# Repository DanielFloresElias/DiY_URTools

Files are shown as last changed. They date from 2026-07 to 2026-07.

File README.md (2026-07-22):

# Herramientas DIY para Robots Colaborativos (UR)

Este proyecto se centra en el **diseño, fabricación e integración de herramientas de bajo coste** para cobots de Universal Robots, utilizando procesos de fabricación DIY (Do It Yourself) y su aplicación en entornos industriales y educativos.

## 📋 Descripción del Proyecto
El objetivo principal ha sido desarrollar un ecosistema de herramientas funcionales (como pinzas y sistemas de iluminación) que se integran nativamente con el software del robot mediante **URCaps**. Esto permite a centros de formación y pequeñas industrias acceder a aplicaciones de robótica colaborativa sin los altos costes de las herramientas comerciales.

## 🚀 Características Técnicas
*   **Controlador:** Basado en ESP32-WROOM-32 con conectividad Ethernet (W5500).
*   **Comunicación:** Protocolo TCP/IP mediante buffers cíclicos de 32 bytes para el intercambio de datos en tiempo real.
*   **Actuadores:** Control de motores con PID y monitorización de corriente.
*   **Interfaz:** Integración completa en PolyScope mediante URCaps personalizadas.

## 📁 Estructura del Repositorio
*   `docs/`: Documentación técnica y especificaciones.
*   `hardware/`: Esquemas eléctricos y diseño de la PCB.
*   `firmware/`: Código C++ para el sistema de control.
*   `software/`: Código de las URCaps y app de configuración.
*   `mecanica/`: Modelos 3D para impresión.
*   `URcaps/`: URcaps para instalar en Polyscope.

## 👥 Centros Participantes
Este proyecto ha sido una colaboración entre:
*   **IES La Valldigna** (Centro coordinador)
*   **IES Jaume Huguet**
*   **Institut Tecnològic de Barcelona**
*   **IES Federica Montseny**
*   **Universal Robots España** (Apoyo técnico y formación)

## 💰 Financiación

Este proyecto ha sido posible gracias a la financiación de las siguientes instituciones:

<table>
  <tr>
    <td align="center" width="33%">
      Ministerio de Educación, FP y Deportes
    </td>
    <td align="center" width="33%">
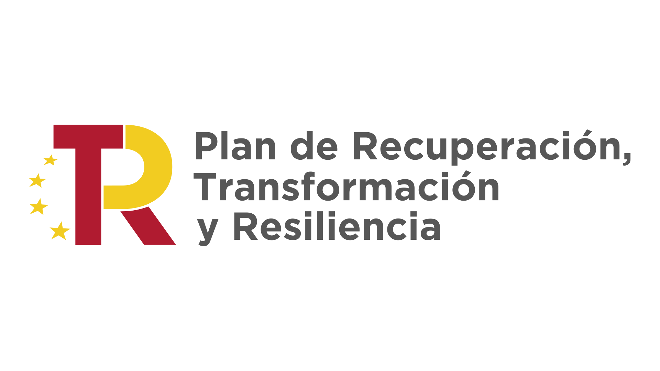
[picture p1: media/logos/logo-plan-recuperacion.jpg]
Plan de Recuperación, Transformación y Resiliencia
      
    </td>
    <td align="center" width="33%">
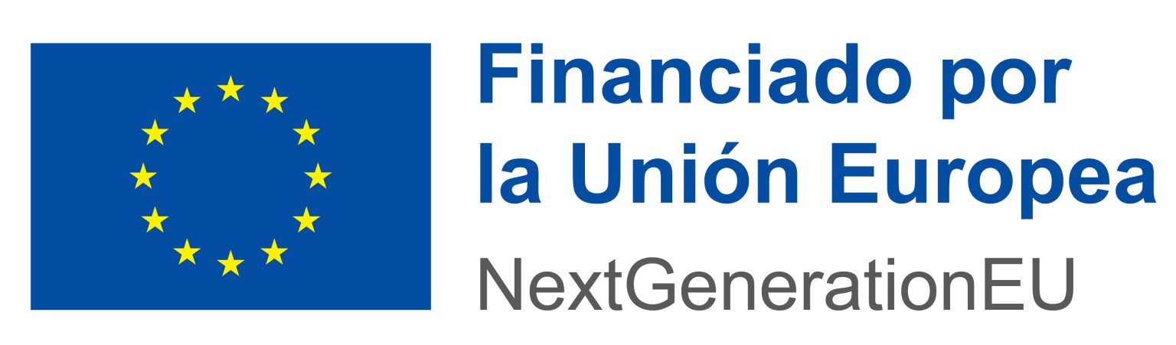
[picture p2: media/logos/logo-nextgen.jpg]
Financiado por la Unión Europea NextGenerationEU
      
    </td>
  </tr>
</table>

Proyecto financiado por el **Ministerio de Educación, Formación Profesional y Deportes** y la **Unión Europea (NextGenerationEU)** en el marco del Plan de Recuperación, Transformación y Resiliencia.

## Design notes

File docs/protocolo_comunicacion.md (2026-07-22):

# Especificaciones del Protocolo de Comunicación DiY_URTools

Este documento detalla el protocolo de intercambio de datos entre el robot Universal Robots (cliente) y la herramienta DiY (servidor TCP) basado en el controlador ESP32.

## 📡 Arquitectura de Red
*   **Protocolo:** TCP/IP Sockets.
*   **Puerto por defecto:** `30002`.
*   **Modo de conexión:** Ciclo de actualización de 100ms (10Hz) para garantizar tiempo real.
*   **Estructura de datos:** Intercambio de tramas fijas de **32 bytes** en ambos sentidos (Full-Duplex).

## 📥 OUT_Buffer (Robot -> Herramienta)
Define las acciones y consignas que el robot envía a la herramienta.

| Byte | Nombre | Descripción | Rango / Valores |
| :--- | :--- | :--- | :--- |
| **0** | **Flags de Acción** | Bits de control (ver detalle abajo) | 8 bits |
| **1** | **Efecto LED** | Tipo de efecto para el anillo luminoso | 0 - 7 |
| **2** | **Consigna (Setpoint)** | Posición deseada de la pinza | 0 (Abierto) - 255 (Cerrado) |
| **3** | **Color 1** | Color principal (ver tabla de colores) | 0 - 15 |
| **4** | **Color 2** | Color secundario para efectos duales | 0 - 15 |
| **5** | **Intervalo** | Velocidad del efecto luminoso | 1 - 255 |

### Detalle de Flags (Byte 0):
*   **Bit 0:** Abrir pinza (Open).
*   **Bit 1:** Cerrar pinza (Close).
*   **Bit 2:** Abrir manual (Override).
*   **Bit 3:** Cerrar manual (Override).

## 📤 IN_Buffer (Herramienta -> Robot)
Contiene la retroalimentación del estado de la herramienta.

| Byte | Nombre | Descripción | Rango / Valores |
| :--- | :--- | :--- | :--- |
| **0** | **Flags de Estado** | Estado de sensores y confirmación | 8 bits |
| **2** | **Posición Actual** | Lectura real del encoder del motor | 0 - 255 |
| **29** | **Modelo** | Identificador del modelo de hardware | ASCII / ID |
| **30-31**| **Firmware Ver.** | Versión del firmware instalada | vX.Y |

## 🎨 Tabla de Colores e Indicadores
El motor de efectos soporta 16 colores predefinidos (Byte 3 y 4), incluyendo:
0: Rojo, 1: Verde, 2: Azul, 3: Amarillo, 4: Magenta, 5: Cian, 8: Blanco, 15: Apagado.

### Efectos Disponibles (Byte 1):
0: Sin efecto, 1: Sólido, 2: Respiración, 3: Knight Rider, 4: Policía, 5: Flash, 6: Arcoíris.
2. Contenido para docs/guia_uso.md
# Guía de Uso e Integración

Esta guía explica cómo poner en marcha las herramientas DiY_URTools e integrarlas en el ecosistema de Universal Robots.

## 🛠️ Requisitos Previos
1.  **Hardware:** PCB DiY_URTools montada con ESP32 y módulo Ethernet W5500.
2.  **Alimentación:** Conector de 12V/24V según el motor utilizado.
3.  **Software:** Robot con PolyScope 5.x o superior.

## ⚙️ Configuración de Red
La herramienta puede configurarse de dos formas:

1.  **Herramienta de Configuración (Python):** Ejecutar `URToolConfigApp` conectando el ESP32 por USB para asignar la IP estática, Máscara y Puerta de enlace.
2.  **Modo Programación:** El firmware incluye un `CONFIGURATION_MODE` que permite el ajuste de parámetros PID (`pinces.setPID(0.4, 0.05, 2.0)`) y límites de fuerza por software para evitar daños en las piezas.

## 🤖 Integración en PolyScope
Para utilizar la herramienta en un programa de robot:

1.  **Instalación de la URCap:** Cargar el archivo `.urcap` generado por el Institut Tecnològic de Barcelona.
2.  **Configuración del Nodo:**
    *   Ir a la pestaña de "Instalación" -> "DiYTool".
    *   Introducir la dirección IP asignada a la herramienta.
    *   Verificar la conexión (el indicador LED de la herramienta debería cambiar de estado).
3.  **Programación:**
    *   Utilizar los nodos de estructura para abrir/cerrar la pinza.
    *   Configurar los efectos visuales para indicar estados (ej: Rojo = Error, Verde = Operación normal).

## ⚠️ Mantenimiento y Seguridad
*   **Detección de pieza:** El sistema monitoriza el consumo de corriente. Si la corriente supera el `gripCurrentThreshold`, la pinza detecta que ha sujetado un objeto y detiene el movimiento.
*   **Watchdog:** El firmware incluye un sistema de seguridad que detiene los motores si se pierde la comunicación TCP con el robot por más de 500ms.

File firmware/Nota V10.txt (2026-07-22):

Aquesta versió incorpora la possibilitat de modificar la configuración de xarxa mitjançant comandes pel port Sèrie.

Com utilitzar les noves comandes Serial
1.Carrega el codi a l'ESP32.
2. Obre el Monitor Serial (a 115200 baudis).
3. Escriu una de les següents comandes i prem ENTER:

Comanda			Funció									Exemple

STATUS			Mostra la configuració IP, MASK i Gateway actualment carregada.		STATUS

IP <adreça>		Canvia temporalment l'adreça IP de l'eina.				IP 192.168.5.100

MASK <adreça>		Canvia temporalment la Subnet Mask.					MASK 255.255.0.0

GW <adreça>		Canvia temporalment el Gateway.						GW 192.168.5.1

SAVE			Guarda permanentment la configuració temporal a l'EEPROM.SAVEREINICIA (Manual)Després de SAVE, has de reiniciar l'ESP32 per aplicar la nova configuració d'Ethernet.(Prem el botó RESET)

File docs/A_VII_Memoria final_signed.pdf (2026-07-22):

ANEXO VII

MODELO DE MEMORIA FINAL DEL PROYECTO

Título del Proyecto: | “Diseño, fabricación e integración de herramientas para robots colaborativos (UR) a partir de procesos de fabricación DIY y aplicación en procesos industriales”
Centro educativo coordinador del proyecto: | IES La Valldigna
Línea o líneas temáticas: | Línea 1, Línea 2, Línea 3, Línea 4, Línea 5, Línea 6
Duración del proyecto: | 20 meses (Sept 2024 - Abril 2026)
Participantes en el proyecto: | IES La Valldigna IES Jaume Huguet Institut Tecnològic de Barcelona IES Federica Montseny
Miembros | Denominación (centro, empresa, entidad) | Funciones desarrolladas | Datos de contacto
Centro coordinador: | IES La Valldigna | Diseño y fabricación de herramienta para el robot colaborativo y su comunicación con el robot | Calle Sant Benet, 249 46760 Tavernes de la Valldigna, València
Participante 2: | Universal Robots España | Formación en robótica colaborativa y apoyo en la programación de UR Caps | Calle Agricultura 106, 08019, Barcelona, Barcelona
Participante 3: | IES Jaume Huguet | Diseño y fabricación de herramienta para el robot colaborativo y su comunicación con el robot | Calle Creu de Cames, SN 43800, Valls, Tarragona
Participante 4: | Institut Tecnològic de Barcelona | Desarrollo del software UR Caps para la comunicación con las distintas herramientas | Calle Aiguablava 121 08033 Barcelona, Barcelona
Participante 5: | IES Federica Montseny | Diseño y fabricación de herramienta para el robot colaborativo | Avenida Primero de Mayo, 4, 46100, Burjassot, Valencia

FORMACIÓN PROFESIONAL

1. Conclusiones sobre la innovación y transferencia conseguidas con el proyecto.
1.1. Breve resumen del proyecto, tras su finalización. Valoración de la relación del proyecto con los objetivos de la convocatoria, a la vista de cómo se ha desarrollado y de cuáles son los resultados conseguidos.

El proyecto “Diseño, fabricación e integración de herramientas para robots colaborativos (UR) a partir de procesos de fabricación DIY y aplicación en procesos industriales” ha permitido un trabajo conjunto entre centros de Formación Profesional de distintas comunidades autónomas y una empresa del sector de la robótica, presentando la oportunidad de compartir conocimientos y experiencias y mejorando la formación técnica del profesorado y, en último término, del alumnado en el ámbito de la robótica colaborativa. El proyecto está basado en el diseño, fabricación, integración y uso didáctico de herramientas de bajo coste para cobots Universal Robots, así como la generación de materiales formativos transferibles a otros contextos educativos y productivos.

El desarrollo del proyecto ha favorecido la colaboración efectiva entre los centros participantes y la empresa generando un entorno en el que se combina la aplicación educativa e industrial y la innovación tecnológica. Esta cooperación ha hecho posible no solo el desarrollo de herramientas plenamente funcionales de bajo coste, sino también la elaboración de documentación técnica, guías, prácticas, video-tutoriales y recursos reutilizables, además de la creación de URCaps y de un repositorio digital orientado a facilitar la replicabilidad del trabajo realizado por otros centros de FP. Entre los logros de este proyecto se encuentran, por tanto, la disponibilidad de herramientas finales utilizables en entornos de simulación de procesos industriales, la generación de materiales didácticos abiertos y la capacitación del alumnado en robótica colaborativa y en tecnologías vinculadas a la industria 4.0.

Durante el proyecto se ha mantenido una relación coherente con los objetivos de la convocatoria ya que ha conectado la formación de alumnado y profesorado con necesidades reales del proceso productivo, ha promovido el aprendizaje basado en retos y proyectos, ha fortalecido la cooperación entre centros y empresa y ha generado productos concretos transferibles al ámbito educativo y empresarial.

Del mismo modo, el proyecto mantiene una vinculación sólida con las líneas temáticas de la convocatoria. Se ha centrado en la innovación tecnológica y en la transferencia de conocimiento entre empresa y centros (Línea 1); ha desarrollado competencias relacionadas con la digitalización, la automatización y la industria 4.0 (Línea 2) y ha impulsado metodologías activas mediante retos interdisciplinares y proyectos vinculados a aplicaciones industriales (Línea 5). Asimismo, el proyecto ha incorporado elementos que relacionados con las vocaciones STEAM haciendo énfasis en la visibilización de la mujer en entornos tecnológicos (Línea 3); con la competencia emprendedora y la conexión con el tejido productivo (Línea 4); y con la creación de redes de colaboración estables e intercambio de conocimiento entre agentes del sector (Línea 6).

En términos generales, podría afirmarse que el proyecto ha cumplido satisfactoriamente con la finalidad de la convocatoria al generar un entorno compartido entre empresa y centros participantes, producir resultados en forma de herramientas para el robot UR tangibles y de valor, enriquecer la capacitación técnica y metodológica de los docentes y ampliar las posibilidades didácticas de los centros educativos en su afán de acercar al alumnado a tecnologías de valor estratégico en la industria actual y futura.

1.2. Descripción del valor añadido del proyecto, con indicación de los beneficios que para los centros educativos ha reportado.

La realización del proyecto ha supuesto un importante valor añadido para los centros educativos participantes, al permitir la movilización de conocimientos previos y su integración con nuevos aprendizajes vinculados a la robótica colaborativa, la fabricación de herramientas de bajo coste, la conectividad industrial y la aplicación didáctica de tecnologías propias de la industria 4.0.

En primer lugar, el proyecto ha contribuido de forma significativa a la mejora de la competencia técnica del profesorado en robótica colaborativa, especialmente en el manejo, programación e integración de robots Universal Robots. Esta formación ha tenido una repercusión directa en el alumnado, ya que los conocimientos adquiridos por los docentes se han transferido al aula mediante actividades prácticas, retos y proyectos vinculados a situaciones próximas al entorno industrial. De este modo, el proyecto no solo ha favorecido la actualización tecnológica del profesorado, sino también la mejora de la calidad de la enseñanza en los ciclos formativos implicados.

Asimismo, el diseño y la construcción de diferentes herramientas para el robot colaborativo ha ampliado notablemente las posibilidades didácticas de los equipos disponibles en los centros. Anteriormente, la explotación didáctica del robot colaborativo se limitaba a herramientas comerciales que limitaban, por su coste, las situaciones de aplicación del robot. Ahora, con las herramientas diseñadas, se amplían.

Otro beneficio relevante ha sido el desarrollo de metodologías activas en el aula, especialmente mediante el aprendizaje basado en retos y proyectos. El alumnado ha podido participar en tareas con un producto final tangible, tomar decisiones técnicas, documentar procesos, ensayar soluciones, detectar errores y proponer mejoras. Esta dinámica ha contribuido al desarrollo de competencias transversales como el trabajo en equipo, la autonomía, la iniciativa, la comunicación técnica y la capacidad de adaptación ante problemas reales.

Además, el proyecto ha generado un beneficio organizativo y pedagógico para los centros, al impulsar la colaboración entre departamentos, familias profesionales y especialidades docentes. La robótica colaborativa ha actuado como eje integrador para conectar conocimientos de automatización, electricidad, electrónica, fabricación mecánica, diseño, programación y comunicaciones industriales. Esta colaboración ha permitido enriquecer las programaciones didácticas y abrir la puerta a futuras actividades intermodulares o proyectos de centro.

Desde el punto de vista de la transferencia, el proyecto ha permitido generar conocimiento y materiales reutilizables que podrán ser aprovechados por los propios centros participantes y por otros centros de Formación Profesional. La elaboración de documentación, guías, tutoriales y recursos vinculados al diseño, fabricación e integración de herramientas DIY para cobots refuerza la sostenibilidad del proyecto y facilita que sus resultados puedan mantenerse y ampliarse más allá del periodo de ejecución.

Por último, el proyecto ha favorecido la creación de una red de colaboración entre docentes de distintos centros educativos y especialidades, lo que ha supuesto un intercambio enriquecedor de experiencias, soluciones técnicas y enfoques metodológicos. Esta cooperación ha permitido comparar realidades educativas diferentes, compartir recursos, resolver dificultades comunes y avanzar en innovación.

1.3. Expectativas de continuidad y/o institucionalización de las actividades realizadas o desarrollos conseguidos en el marco del proyecto.

La valoración positiva de los resultados alcanzados permite prever la continuidad de varias de las actividades, metodologías y desarrollos generados en el marco del proyecto. Más allá de la ejecución de las acciones previstas, el proyecto ha creado una base técnica, metodológica y organizativa que podrá ser aprovechada por los centros participantes en cursos posteriores.

En primer lugar, se prevé consolidar el uso de metodologías activas, especialmente el aprendizaje basado en retos y el aprendizaje basado en proyectos, como estrategia para favorecer la implicación del alumnado y el desarrollo de competencias profesionales y transversales. Este enfoque ha permitido trabajar no solo contenidos técnicos vinculados a la robótica colaborativa, sino también habilidades como la autonomía, la resolución de problemas, la comunicación técnica, la toma de decisiones, la creatividad y el trabajo en equipo.

Asimismo, los conocimientos adquiridos por el profesorado y el alumnado en el diseño, fabricación e integración de herramientas para robots colaborativos permitirán seguir desarrollando nuevas aplicaciones didácticas en el futuro. La experiencia acumulada durante el proyecto abre la posibilidad de crear nuevos prototipos, mejorar los ya desarrollados y adaptar las soluciones generadas a otros módulos, ciclos formativos o necesidades concretas del entorno productivo.

Otro elemento que favorece la continuidad es la generación de materiales, documentación técnica, guías y recursos didácticos derivados del proyecto. Estos productos podrán incorporarse a las programaciones de distintos módulos profesionales y reutilizarse con nuevas promociones de alumnado, lo que contribuye a institucionalizar los aprendizajes obtenidos.

De igual modo, la colaboración entre los centros participantes representa una de las principales líneas de continuidad. La comunicación establecida durante el proyecto ha permitido compartir experiencias, resolver dificultades técnicas y metodológicas, contrastar soluciones y enriquecer la práctica docente. Esta red de trabajo podrá mantenerse para futuras colaboraciones, nuevas propuestas de innovación o actividades intercentros relacionadas con la robótica colaborativa, la automatización industrial, la fabricación digital o la industria 4.0.

Finalmente, la continuidad del proyecto podrá verse reflejada en la actualización progresiva de las programaciones didácticas, la incorporación de nuevas prácticas con robots colaborativos, la ampliación de los recursos disponibles en los talleres y la consolidación de una cultura de innovación aplicada en los centros. De este modo, los desarrollos conseguidos no se limitan a los productos generados durante el proyecto, sino que contribuyen a transformar de manera estable la forma en que se enseña y se aprende la robótica colaborativa en la Formación Profesional.

2. Memoria económica.
2.1. Cuantía total de la subvención recibida.

La cuantía total de la subvención recibida asciende a 120.000 €, recibiendo cada centro educativo 30.000 € y 0 € la empresa Universal Robots.

2.2. Gastos desagregados por participantes en el proyecto.
Miembros | Denominación (centro, empresa, entidad) | Funciones desarrolladas | Datos de contacto
Centro coordinador | IES La Valldigna | Centro coordinador. Diseño e implementación de herramientas | Calle Sant Benet, 249 46760 Tavernes de la Valldigna, València
Integrante 2 | Institut Jaume Huguet | Diseño e implementación de herramientas | Calle Creu de Cames, SN 43800, Valls, Tarragona
Integrante 3 | Institut Tecnològic Barcelona | Diseño y programación de URCaps | Calle Aiguablava 121 08033 Barcelona, Barcelona
Integrante 4 | IES Federica Montseny | Diseño e implementación de herramientas | Avenida Primero de Mayo, 4, 46100, Burjassot, Valencia
Integrante 5 | Universal Robots | Formador en robótica colaborativa | Calle Agricultura 106, 08019, Barcelona, Barcelona

3. Desarrollo del proyecto.
3.1. Índice de las acciones previstas inicialmente y que constaban en la Memoria técnica del proyecto.

En la siguiente tabla se especifican las diferentes fases y bloques de trabajo previstas inicialmente:

Fases | Bloque de trabajo
1 | Gestión del proyecto | 1.1 Coordinación de participantes y creación de un sistema de archivos compartido.

1.2 Elaboración de memoria inicial, de progreso y final.

2

Formación
profesorado robótica
colaborativa

2.1 Implementación y montaje de un sistema robótico de Universal Robots para realizar un proceso industrial.
2.2 Programación básica y avanzada de cobots de Universal Robots.

3

Estudio, diseño y
simulación digital de
herramientas

3.1 Estudio de las herramientas robóticas en aplicaciones industriales y sus principales características.
3.2 Diseño digital de herramientas robóticas mediante 3D CAD, implementando modelos de virtualización (gemelo digital)

4

Fabricación e
integración de las
herramientas de bajo
coste en robot UR

4.1 Estudio de procesos de fabricación en la industria clásica y las nuevas técnicas, métodos y materiales surgidos en la industria actual.
4.2 Implementación de procesos de fabricación por sustracción o deposición a partir de los modelos 3D CAD diseñados por los estudiantes. 4.3 Integración electrónica (hardware), programación de firmware (URCaps) y software para el control de la herramienta en la aplicación robótica.

5

Formación del
alumnado en robótica
colaborativa

5.1 Implementación y montaje de un sistema robótico de Universal Robots para realizar un proceso industrial.
5.2 Programación básica y avanzada de cobots de Universal Robots 5.3 Implementación de aplicaciones industriales de la industria local.

6

Retos a nivel centro
robótica colaborativa

6.1 Realización de aplicaciones industriales con cobots y con las herramientas diseñadas, verificando la funcionalidad de estas.
6.2 Realización de una jornada (“skills”) en cada centro para valorar las mejores herramientas diseñadas y sus prestaciones en entornos productivos con cobots.

7

Jornada de retos
intercentros robótica
colaborativa

7.1 Exponer y analizar el proceso de fabricación de herramientas de bajo coste a compañeros de otros centros educativos.
7.2 Realización de una jornada intercentros mediante un concurso del uso de cobots en aplicaciones industriales, así como diseño e implementación de herramientas low cost.

8

Elaboración de
documentación para
el desarrollo de
herramientas DIY

8.1 Realización de un repositorio de documentación para guiar a diseñar, fabricar e integrar herramientas “low cost” para cobots en función de las necesidades de la aplicación industrial.
8.2 Realización de un repositorio de documentación para programar robots colaborativos de UR, integrando herramientas de diseño propio en entornos industriales.
9 | Evaluación | 9.1 Análisis de la ejecución del proyecto, identificando fortalezas y

y difusión del
proyecto

debilidades, promoviendo posibles mejoras.
9.2 Difundir y compartir la documentación del proyecto a otros centros.
3.2. Descripción de las acciones en las que se ha desarrollo finalmente el proyecto. Indique las causas de las variaciones que se hayan producido entre previstas y las ejecutadas finalmente.

En la siguiente tabla se puede observar las fases y bloques de trabajo que finalmente se han realizado en la ejecución del proyecto.

Fases | Bloque de trabajo
1 | Gestión del proyecto | - Organizar las reuniones por videoconferencias entre los centros y empresa, fijando las sesiones de trabajo y fomentando el trabajo en equipo. - Fijar un calendario de fechas para las convocatorias y orden día de las reuniones presenciales o virtuales y velar por su cumplimiento. - Organizar y adaptar las programaciones de los módulos. - Coordinar las tareas adjudicadas a los centros docentes y empresa. - Realización las diferentes memorias para la ejecución del proyecto.
2 | Formación profesorado robótica colaborativa | - Realizar curso de formación de Universal Robots en robótica colaborativa. - Instalar la estación del sistema robótico (controladora, teach pendant, brazo y herramientas) en los diferentes centros educativos.
3 | Estudio, diseño y simulación digital de herramientas | - Visita empresas locales y observar los procesos industriales con robots. - Establecer la elección de dos herramientas funcionales para robots, una común para todos los centros educativos(pinza), otra específica del entorno industrial local. - Establecer grupos de alumnado para el diseño de las herramientas. - Diseñar herramientas de bajo coste en software 3D-CAD. - Documentar todo el proceso al que se han enfrentado el alumnado.
4 | Fabricación e integración de las herramientas de bajo coste en robot UR | - Fabricar las herramientas mediante sustracción (CNC) y/o impresión 3D. - Implementar el sistema de control de los actuadores y la electrónica de las herramientas. - Desarrollar las URcaps para la comunicación de la herramienta con el robot. - Documentar todo el proceso al que se han enfrentado el alumnado.
5 | Formación del alumnado en robótica colaborativa | - Formar al alumnado de los diferentes centros educativos en: 1. Elementos que forman el sistema robótico, instalación y aplicaciones. 2. Programación básica y avanzada de un robot colaborativo UR.
6 | Retos a nivel centro robótica colaborativa | - Realizar durante el curso escolar, talleres de formación en diseño de herramientas de bajo coste mediante impresión 3D y en robótica colaborativa, para el alumnado de la ESO y Bachillerato. - Establecer grupos de trabajo de alumnado para la jornada de retos. - Preparar puestos de trabajo para la realización de la actividad o jornadas.

| | - Realizar las jornadas de retos o “skills” en robótica colaborativa, simulado procesos industriales locales, abiertas, tanto a alumnado de FP, como de ESO y Bachillerato. - Documentar las jornadas y el reto al que se han enfrentado el alumnado.
7 | Jornada de retos intercentros robótica colaborativa | - Visitar empresa UR y presentar las herramientas diseñadas. - Documentar las jornadas y el reto al que se han enfrentado el alumnado.

8

Elaboración
de
documentaci
ón para el
desarrollo de
herramientas
DIY
- Establecer un modelo de guion de tutoriales o prácticas para la fabricación de herramientas de bajo coste.
- Elaborar documentación y guiones con los pasos a seguir para la fabricación de las herramientas (diseños, planos, electrónica, integración, etc.).
- Realizar videotutoriales registrando la instalación, la configuración y uso de la herramienta de bajo coste en una aplicación industrial automatizada, teniendo en cuenta la selección de profesorado y alumnado, fomentando la igualdad de género, e incluso realizar una discriminación positiva de sexo femenino y el acceso a las STEAM de las mismas.

9

Evaluación
y difusión del
proyecto
- Establecer los ítems evaluables de cada fase del proyecto.
- Identificar en cada una de las fases del proyecto los ítems que no se han cumplido y aplicar, en caso de ser necesario, las medidas correctoras en cada una de ellas.
- Compartir durante el tiempo de realización del proyecto a través de página web del centro y redes sociales de este, las diferentes fases y acciones que se han ido realizando, teniendo en cuenta la paridad de sexos, e intentando promover el acceso de la mujer a los estudios STEAM.
- Compartir a la finalización del proyecto, todo tipo de material realizado durante el trascurso de este, a través de multitud de canales de difusión como pueden ser, webs, revistas educativas, webs de recursos educativos, webs de formación de profesorado

Debido a la complejidad del proyecto y a las horas necesarias para la implementación de herramientas, el punto 6, Retos a nivel centro robótica colaborativa, no se realizaró en el transcurso del proyecto. Así, la jornada “skills” realizada en cada centro solo fue realizada por el IES La Valldigna. En el resto, la falta de tiempo en el curso escolar, al coincidir con el período de formación en empresa, hizo imposible la organización de dicha actividad.

Respecto a la fase 7, Jornada de retos intercentros robótica colaborativa, no fue posible la participación del alumnado que desarrolló mediante retos las herramientas digitales en la jornada intercentros. En su lugar, el profesorado compartió las experiencias y los aprendizajes obtenidos.

4. Resultados finales.
4.1. Productos / Resultados tangibles e intangibles.

Entre los resultados y productos obtenidos mediante el presente proyecto se pueden enumerar:

1. Desarrollo, diseño, fabricación e integración de tres herramientas realizadas a partir de impresión 3D y electrónica de consumo básica, siguiendo la filosofía “Do It Yourself” para la aplicación en robots colaborativos UR. Esto incluye el desarrollo de dos URCaps para el manejo de las diferentes herramientas en la programación del robot.
2. Elaboración de un conjunto de documentos, guías, prácticas y videotutoriales para el diseño y fabricación de herramientas low cost, junto a su posterior integración en robots colaborativos y su uso en procesos industriales automatizados.
3. Formación académica tanto del profesorado como alumnado en robótica colaborativa y aplicación de esta en procesos industriales.
4. Desarrollo de programaciones didácticas de los módulos participantes en el proyecto aplicando el trabajo multidisciplinar a través de metodologías activas de aprendizaje colaborativo basado en retos (ACBR) o proyectos (ACBP).
5. Transferencia de conocimientos en robótica colaborativa desde los institutos a empresas locales, facilitando la formación en esta tecnología y creando sinergias de colaboración entre empresas y centros educativos.
6. Promocionar la Formación Profesional y las titulaciones STEAM en toda la comunidad educativa de los centros que forman parte del proyecto, desde los primeros cursos de la ESO hasta bachillerato, rompiendo barreras, roles y estereotipos de género, mediante el trabajo educativo con los departamentos de informática o tecnología de la ESO, acercando así la tecnología de la robótica al alumnado desde edades tempranas.
4.2. Impacto.

Una vez obtenidos los resultados derivados del proyecto, cabe valorar su impacto en los centros educativos participantes.

En primer lugar, el impacto sobre el alumnado ha sido especialmente relevante al comprobar que mediante el proyecto han adquirido competencias profesionales relacionadas con la automatización industrial, la robótica, la fabricación, la electrónica, la programación y la resolución de problemas técnicos. Además, el alumnado ha podido enfrentarse a situaciones próximas a la realidad productiva, siendo capaces de encontrar soluciones a problemas propios del sector industrial.

Sin abandonar el punto de vista competencial, el proyecto ha contribuido al desarrollo de capacidades transversales como el trabajo en equipo, la autonomía, la toma de decisiones, la creatividad, la comunicación técnica y la capacidad de análisis ante errores o dificultades. La aplicación de metodologías activas ha permitido que el alumnado asumiera un papel más activo en su aprendizaje, participando en tareas que conducían a la obtención de un producto final tangible y funcional.

El impacto sobre el profesorado también ha sido notable. La participación en el proyecto ha favorecido la actualización técnica en robótica colaborativa, diseño de herramientas, integración de sistemas y aplicación de tecnologías vinculadas a la industria 4.0. Esta mejora de la capacitación docente ha repercutido directamente en la calidad de las actividades diseñadas para el alumnado y ha generado mayor seguridad para incorporar este tipo de tecnologías en futuras prácticas, proyectos o situaciones de aprendizaje.

A nivel de centro, el proyecto ha supuesto una mejora en el aprovechamiento didáctico de los recursos tecnológicos disponibles. El robot colaborativo ha pasado de ser un recurso de uso limitado a convertirse en un eje de trabajo flexible, capaz de articular actividades intermodulares y proyectos vinculados a distintos ámbitos profesionales.

Asimismo, el proyecto ha tenido un impacto positivo en la organización interna de los centros, al favorecer la coordinación entre profesorado de diferentes módulos, ciclos formativos y especialidades.

Otro impacto destacable ha sido la creación de una red de colaboración entre los centros participantes. El intercambio de experiencias, soluciones técnicas, materiales y enfoques metodológicos ha permitido enriquecer la práctica docente y generar una base de trabajo común para futuras actuaciones.

No podemos olvidar el impacto en la difusión de la Formación Profesional y de las titulaciones STEAM dentro de la comunidad educativa. Las actividades desarrolladas han permitido promocionar los ciclos y centros participantes, favoreciendo que la robótica colaborativa sea un ámbito profesional atractivo y con proyección de futuro. en general y en las mujeres en particular.

Finalmente, no debemos menospreciar el potencial impacto que genera en el entorno productivo local al acercar al alumnado y al profesorado a aplicaciones industriales reales o simuladas. Sin duda el proyecto ha incentivado en la preparación del alumnado como futuros/as profesionales del sector.

4.3. Otros resultados no esperados.

Entre los resultados no esperados observados tras la realización del proyecto destaca, en primer lugar, el cambio de percepción sobre las posibilidades didácticas de los robots Universal Robots. Antes del desarrollo del proyecto, el robot UR podía percibirse como un recurso con aplicaciones limitadas o condicionado por el uso de herramientas comerciales específicas. Sin embargo, la exploración de sus opciones de conectividad, programación e integración mediante URCaps ha permitido comprobar que se trata de una herramienta didáctica flexible, adaptable y reutilizable en múltiples situaciones de aprendizaje.

Además, aunque el trabajo interdisciplinar ya estaba previsto en la memoria inicial, el conocimiento adquirido sobre estas posibilidades ha abierto nuevas vías de coordinación entre módulos, departamentos y familias profesionales dentro de los centros educativos. La robótica colaborativa ha demostrado ser un eje integrador capaz de conectar contenidos relacionados con la automatización, la programación, la fabricación mecánica, la electrónica, las comunicaciones industriales, la visión artificial y el diseño de procesos.

En esta línea, durante el diseño, fabricación y prueba de las herramientas han surgido nuevas ideas de aplicación que no estaban contempladas inicialmente. Entre ellas, pueden destacarse el desarrollo de nuevas pinzas, útiles específicos para sistemas de visión artificial, elementos auxiliares para procesos de paletizado o dispositivos destinados al control de componentes externos al propio robot, como mesas de utillaje, estaciones de trabajo o pequeños sistemas automatizados complementarios.

Otro resultado no esperado ha sido la detección de nuevas necesidades relacionadas con los espacios, los recursos y la organización de las aulas-taller. El desarrollo del proyecto, junto con la interacción entre los centros participantes, ha permitido identificar carencias y oportunidades de mejora en los entornos formativos, tanto en lo relativo a la distribución y adecuación de espacios como a la disponibilidad de determinados elementos de automatización presentes actualmente en el sector industrial. En este sentido, se han identificado como posibles líneas de mejora o ampliación futura la construcción de cintas transportadoras de bajo coste, la incorporación de tecnología IO-Link, la comunicación mediante RS485 u otros sistemas de interconexión industrial.

Por último, el proyecto ha tenido también un efecto positivo en la difusión interna de la innovación dentro de los propios centros. La participación en esta convocatoria ha permitido que docentes de otros ciclos formativos y especialidades conozcan de primera mano las posibilidades que ofrecen los proyectos de innovación aplicada en Formación Profesional. Este hecho puede favorecer la participación futura de nuevos equipos docentes en iniciativas similares, ampliando el impacto del proyecto más allá de los departamentos directamente implicados.

4.4. Indicar las causas de posibles variaciones y/o desajustes entre los resultados previstos (recogidos en la Memoria técnica del proyecto) y los resultados finalmente conseguidos.

En términos generales, las desviaciones entre los resultados previstos en la memoria técnica inicial y los resultados finalmente obtenidos han sido reducidas. El proyecto ha mantenido su rumbo principal y ha permitido alcanzar los objetivos esenciales.

No obstante, durante el desarrollo del proyecto se han producido algunos ajustes derivados de la complejidad técnica de las actuaciones realizadas y de determinadas circunstancias organizativas. En el planteamiento inicial podría contemplarse la posibilidad de generar más de una herramienta por centro educativo, dado que el número de alumnado participante permitía organizar diferentes grupos de trabajo. Sin embargo, el proceso de diseño, fabricación, programación e integración de herramientas plenamente funcionales para robots colaborativos requiere un conocimiento técnico amplio y una coordinación precisa entre varias áreas: diseño mecánico, fabricación, electrónica, programación, conectividad y validación funcional. Por este motivo, se centraron los esfuerzos en el desarrollo de una herramienta principal, con el acompañamiento directo del equipo docente.

También se han producido algunas variaciones dentro de las programaciones didácticas de los módulos implicados. Aunque las actuaciones previstas se incorporaron a la planificación docente, su desarrollo concreto tuvo que adaptarse a diferentes imprevistos surgidos durante el curso, como jornadas de huelga del alumnado, retrasos en la recepción de determinados materiales o bajas del profesorado.

En relación con la promoción de la Formación Profesional, esta promoción se ha ampliado a otros ámbitos. Si bien se contemplaba la difusión del proyecto dentro de la comunidad educativa de los centros participantes, las actividades realizadas han permitido ampliar dicha promoción a otros contextos y destinatarios. El trabajo desarrollado se ha mostrado en jornadas de puertas abiertas, visitas de alumnado de Educación Primaria y actividades con personas externas a los centros, incluyendo visitantes vinculados a programas Erasmus.

Por todo ello, no se podría considerar que las variaciones observadas hayan supuesto una desviación negativa respecto al planteamiento inicial, sino una adaptación razonable que debería tenerse en cuenta en la realización de futuros proyectos.

5. Seguimiento y evaluación del proyecto.
5.1. Descripción y valoración del plan de seguimiento y evaluación del proyecto llevado a cabo. Valoración del grado de ajuste del proyecto a lo previsto inicialmente.

Para valorar el proyecto se confeccionó en la memoria inicial la siguiente rúbrica, teniendo en cuenta las fases de temporalización previamente descritas y múltiples factores.

Plan seguimiento y evaluación del proyecto | Escala de valoración
D e fi c i e n t e | R e g ul a r | B i e n | M u y bi e n
Fase | Ítem | 1 | 2 | 3 | 4
FASE 1 | 1.1 Se ha establecido un plan de trabajo, realizando la coordinación y la adjudicación de tareas. | | | X
| 1.2 Se han realizado las diferentes memorias del proyecto. | | | | X
Puntuación FASE 1 | | 7/8
FASE 2 | 2.1 Se ha formado al profesorado de los diferentes centros educativos en robótica colaborativa. | | | | X
Puntuación FASE 2 | | 4/4
| 3.1 Se ha formado al alumnado fomentando el I+D+i para el diseño de | | | X

FASE 3 | herramientas robóticas en aplicaciones industriales locales.
| 3.2 Se han desarrollado competencias profesionales en el alumnado ligadas al diseño asistido por computadora (CAD). | | | X
| 3.3 Se han Implementado metodologías activas de aprendizaje colaborativo basadas en proyectos o retos. | | | | X
Puntuación FASE 3 | | 10/12
FASE 4 | 4.1 Se ha formado al alumnado en procesos de fabricación mediante diferentes tecnologías. | | | X
| 4.2 Se ha desarrollado la interconectividad y comunicación entre la herramienta y el sistema robótico. | | | X
| 4.3 Se han implementado metodologías activas de aprendizaje colaborativo basadas en proyectos o retos. | | | | X
Puntuación FASE 4 | | 10/12
FASE 5 | 5.1 Se ha formado al alumnado de los diferentes centros educativos en robótica colaborativa. | | | X
Puntuación FASE 5 | | 3/4
FASE 6 | 6.1 Se ha difundido para todo el alumnado del centro la jornada de retos. | X
| 6.2 Se han realizado las jornadas de competición sobre robótica colaborativa. | X
| 6.3 Se han ejecutado metodologías activas de aprendizaje colaborativo basado en proyectos o retos. | X
Puntuación FASE 6 | | 3/12
FASE 7 | 7.1 Se han realizado las jornadas de competición sobre robótica colaborativa. | | X
| 7.2 Se han aplicado metodologías activas de aprendizaje colaborativo basado en proyectos o retos. | X
| 7.3 Se ha realizado el intercambio de experiencias educativas entre los diferentes centros educativos. | | | | X
Puntuación FASE 7 | | 7/12
FASE 8 | 8.1 Se ha realizado un repositorio de documentación (tutoriales y videotutoriales) siguiendo los ítems marcados. | | | X
Puntuación FASE 8 | | 3/4

FASE 9 | 9.1 Se ha realizado la vigilancia por el correcto cumplimiento de las fases del proyecto y lo que conlleva. | | X
| 9.2 Se han establecido los resultados finales obtenidos y sus conclusiones y mejoras. | | X
| 9.3 Se ha compartido la documentación del proyecto. | | X
Puntuación FASE 9 | | 9/12
5.2. Descripción de los principales desajustes, especificando sus causas, la naturaleza de tales desviaciones o no conformidades (de carácter técnico, de coordinación, de gestión u otros).

Como podemos observar en la tabla anterior, los principales desajustes se producen en la fase 6 y 7.

En cuanto a la fase 6, aunque bien es cierto que la difusión en el propio centro educativo sí se ha realizado de forma conveniente, las jornadas de competición sobre robótica colaborativa e integración se realizaron exclusivamente en el IES La Valldigna. En los otros institutos no fue posible la celebración de estas debido a la falta de espacio espacio temporal.

La fase 7 tampoco pudo llevarse a cabo como se había planeado previamente. La competición o “skills” intercentros no se pudo llevar a cabo porque el alumnado que había sido elegido para llevarlo a cabo se encontraba en el período de formación en empresa y no podía realizar esta actividad. En su lugar, la jornada intercentros se planificó como una jornada de reunión de puesta en común de las herramientas creadas, perfeccionamiento de las mismas e intercambio de experiencias en la implementación de los retos planteados en los respectivos módulos. También se tuvo la oportunidad de mostrar a docentes de otros centros el trabajo realizado en las instalaciones de Universal Robots en Barcelona.

5.3. Medidas aplicadas para facilitar el ajuste del proyecto en su inicio, desarrollo y cierre, si procede.

Como forma de controlar el correcto desarrollo del proyecto, se han mantenido reuniones online tratadas como puesta en común del trabajo realizado hasta ese momento y de coordinación.

Por otra parte, en diciembre de 2025 se realizó una reunión presencial de dos días en el IES Federica Montseny. En estas jornadas se tuvo la oportunidad de observar las metodologías de trabajo del centro y realizar las primeras pruebas y ajustes entre las herramientas y las URCaps programadas por el IT Barcelona.

6. Difusión y explotación de los resultados, en su caso.

6.1. Descripción de las acciones, soportes y/o instrumentos utilizados para difundir el proyecto y sus resultados hasta la fecha de elaboración de la Memoria, si procede.

El plan de difusión y la explotación de los resultados del proyecto se han realizado en la fase 9, tal y como se establecía en la memoria inicial. Las acciones de difusión y explotación son las siguientes:

Acciones | Destinatarios | Acciones, soportes y/o instrumentos
Difusión en redes sociales | Comunidad educativa | Compartir las acciones del transcurso del proyecto
Documentación del proyecto | Centros educativos | Compartir la documentación generada en repositorios de recursos docentes.
Comunicación empresas | Empresas y centros tecnológicos | Hacer llegar a las empresas colaboradoras la información del proyecto y la posible aplicación de la robótica colaborativa
Comunicación revistas y webs temáticas | Usuarios/as y profesionales del sector de la automatización | Compartir con revistas y webs del sector de la robótica y automatización industrial la información del proyecto
Publicación en Redes de Innovación | Otros centros educativos | Publicación del proyecto a través de la Red de Innovación de Cataluña y de la Comunidad Valenciana
Informar centros adyacentes | Otros centros educativos | Enviar correos a centros próximos para informar del proyecto y la posibilidad de compartir todo el material generado en la ejecución de este
Difusión en ferias educativas | Futuro alumnado | Compartir el proyecto en diferentes ferias educativas promocionando la FP, titulaciones STEAM y las nuevas tecnologías como la robótica colaborativa
Difusión por parte de Universal Robots | Clientes y usuarios de Universal Robots | La empresa difundirá el proyecto a través de sus canales de comunicación, así como en las diferentes charlas o ferias a las que asista

6.2. Resultados conseguidos con la difusión del proyecto y sus resultados, si procede.

Las acciones llevadas a cabo han permitido dar visibilidad al proyecto y los principales resultados obtenidos tanto dentro de los centros participantes como en otros espacios educativos y profesionales.

En primer lugar, la publicación de la información del proyecto a través de las redes sociales de los diferentes centros ayuda a que la comunidad educativa viera el trabajo realizado tanto por docentes como alumnado y los productos desarrollados.

La difusión también ha contribuido a reforzar la imagen de los centros participantes como centros comprometidos con la innovación aplicada, la actualización tecnológica y la transferencia de conocimiento en Formación Profesional.

Asimismo, la exposición del proyecto en jornadas, visitas, actividades de puertas abiertas u otros encuentros educativos ha favorecido la promoción de la Formación Profesional y, particularmente de las titulaciones STEAM, como opción educativa atractiva y con proyección profesional. En este sentido, ha tenido un efecto positivo en la orientación académica y profesional del alumnado tanto propio del centro como de fuera de él.

Otro resultado destacable ha sido el interés generado entre otros docentes. La difusión interna del proyecto ha permitido que profesorado no directamente implicado conociera las posibilidades de participar en proyectos de innovación aplicada. Esto puede favorecer futuras colaboraciones interdisciplinares, nuevos proyectos de innovación en el centro y una mayor integración de metodologías activas.

En relación con otros centros educativos, la difusión del proyecto y sus resultados abren la posibilidad de que los materiales generados sean aplicados. Al compartir los materiales se abre la posibilidad que otros docentes puedan adaptar o reproducir experiencias similares en sus contextos formativos, mejorando así la calidad educativa.

Por otra parte, la comunicación del proyecto a empresas y agentes vinculados al sector industrial ha contribuido a visibilizar el papel de la Formación Profesional como espacio de innovación aplicada y como puente entre la educación y el tejido productivo. También ha despertado el interés de empresas para futuras colaboraciones en futuros proyecto de innovación.

Por último, la difusión del proyecto ha favorecido que el proyecto tenga continuidad en cursos posteriores, planteando situaciones de aprendizaje similares mediante retos, reutilizando los recursos elaborados, mejorando las herramientas diseñadas y desarrollando nuevas aplicaciones didácticas.

7. Valoración de la participación en la convocatoria.
7.1. Reflexión sobre los beneficios obtenidos a partir de esta participación.

Una vez finalizado el proyecto de innovación, la reflexión general por parte de los centros educativos participantes es altamente positivo.

En primer lugar se destaca el poder disponer de un conjunto de herramientas finales a bajo coste compatibles con el robot UR. La incorporación de estas herramientas amplía las posibilidades didácticas del robot UR y acercar las situaciones de aprendizaje a procesos industriales más cercanas a la realidad como empaquetados, paletizados o dispensación de productos. Cabe destacar la obtención de las URCaps para el manejo de estas herramientas, útiles para las herramientas ya diseñadas y para las futuras, que facilitan la implementación de las mismas dándoles un carácter más profesional.

La formación recibida por parte de los docentes ha implicado una mayor seguridad a la hora de impartir docencia transmitir

De la misma manera se valora el impacto que el proyecto ha tenido en la formación del alumnado. La implicación del alumnado en el desarrollo de los materiales obtenidos ha sido notable desarrollando de esta forma las competencias profesionales de los ciclos formativos.

A nivel educativo, la realización del proyecto y su correspondiente dotación económica ha dado acceso a material educativo que, por su coste, no está disponible normalmente en las aulas-taller.

7.2. Dificultades encontradas.

En la realización del proyecto se han encontrado diferentes circunstancias que han dificultado su desarrollo.

En primer lugar, la complejidad de un proyecto que ha combinado diseño mecánico, fabricación 3D (o incluso mecanizado), electrónica, programación, comunicaciones y conocimientos de robótica ha hecho necesario dedicar más tiempo del que previamente se necesitaba a pruebas, ajustes y validaciones.

En esta misma línea, aunque el proyecto incluía formación, pasar de una formación inicial a un manejo de funciones avanzadas del robot ha requerido un proceso de experimentación, resolución de problemas y consolidación de conocimientos.

Por otra parte, ajustar los tiempos de desarrollo del proyecto al calendario escolar real ha requerido un esfuerzo extra por parte de los docentes implicados. La coincidencia con evaluaciones, actividades propias del curso, posibles jornadas de huelga, períodos de prácticas del alumnado o bajas puntuales del profesorado ha obligado a reajustar algunas sesiones y a redistribuir determinadas tareas.

El planteamiento al alumnado de un reto tan abierto también ha provocado que los materiales necesarios para la ejecución del proyecto fueran de naturaleza variada y sujeto a diversas modificaciones. La búsqueda de materiales muy específicos y los retrasos en su entrega han significado un desafío añadido.

Por último, aunque se han obtenido resultados satisfactorios, la coordinación entre centros ubicados en diferentes territorios también ha supuesto un reto organizativo. Las diferencias de calendario escolar, disponibilidad horaria, ritmos de trabajo y organización interna de cada centro han requerido una comunicación constante y una planificación flexible para mantener la coherencia del proyecto común. En este apartado también se debe destacar el esfuerzo extra que supone por parte de los docentes implicados, dado que el proyecto ha requerido de una dedicación temporal adicional a lo que es la actividad educativa común.

7.3. Sugerencias de mejora.

Una vez finalizado el proyecto, cabe la necesidad de reflexionar las oportunidades de mejora.

La temporalización educativa siempre es un reto debido a los imprevistos y diferentes ritmos del alumnado. Aprender de los errores y ajustar mejor las fases de realización del proyecto es sin duda un punto de mejora.

Por otra parte, la carga de trabajo extra que supone la realización de un proyecto de innovación de esta envergadura requiere una mayor colaboración y participación del profesorado de los centros. Por ello, animar y motivar a otros compañeros/as docentes será necesario en futuros proyectos.

Por último, fruto de los aprendizajes y experiencias adquiridos, si se abordara el proyecto de nuevo se tendría en cuenta todas esas dificultades anteriormente mencionadas y, por tanto mejorar la realización del proyecto.

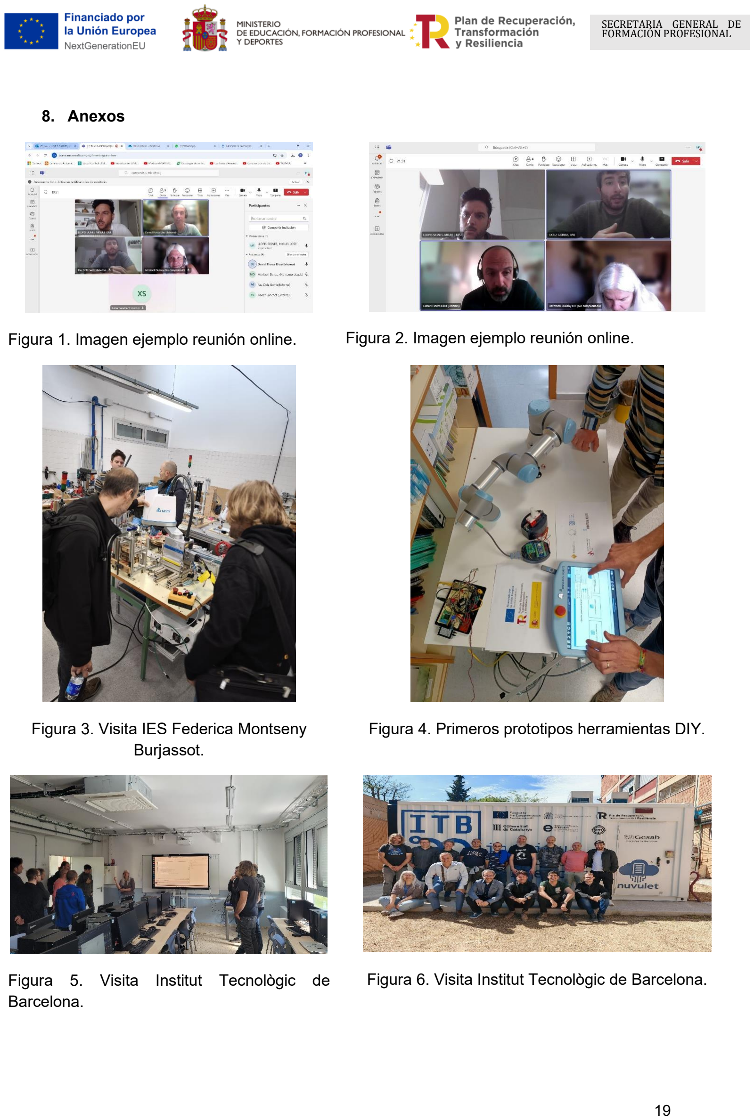
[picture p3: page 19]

### 8. Anexos

Figura 1. Imagen ejemplo reunión online. | Figura 2. Imagen ejemplo reunión online.

Figura 3. Visita IES Federica Montseny Burjassot.

Figura 4. Primeros prototipos herramientas DIY.

Figura 5. Visita Institut Tecnològic de Barcelona.

Figura 6. Visita Institut Tecnològic de Barcelona.

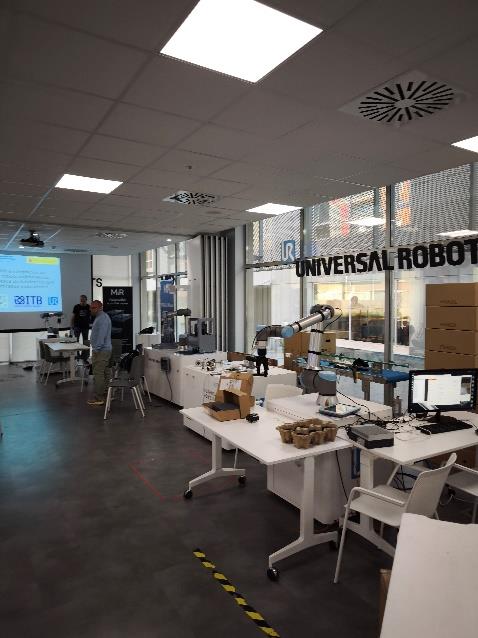
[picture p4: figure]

Figura 7. Visita sede Universal Robots Barcelona.

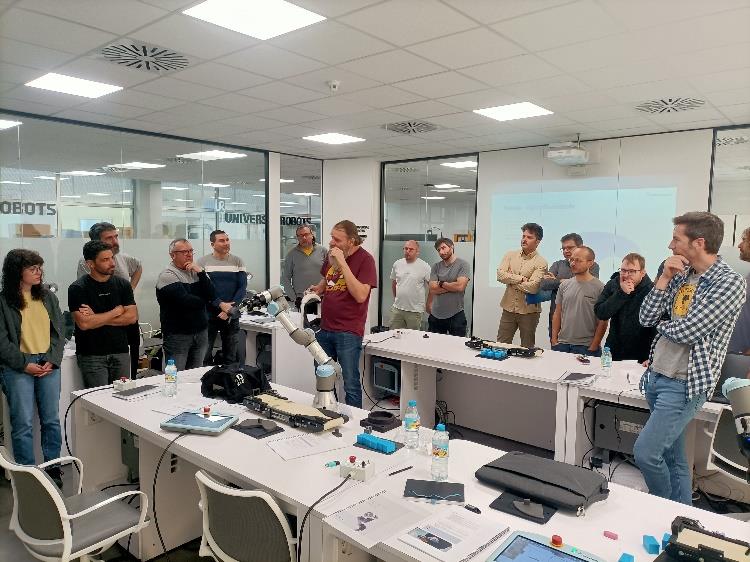
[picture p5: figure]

Figura 8. Transferencia conocimentos a centros educativos de diferentes zonas del estado.

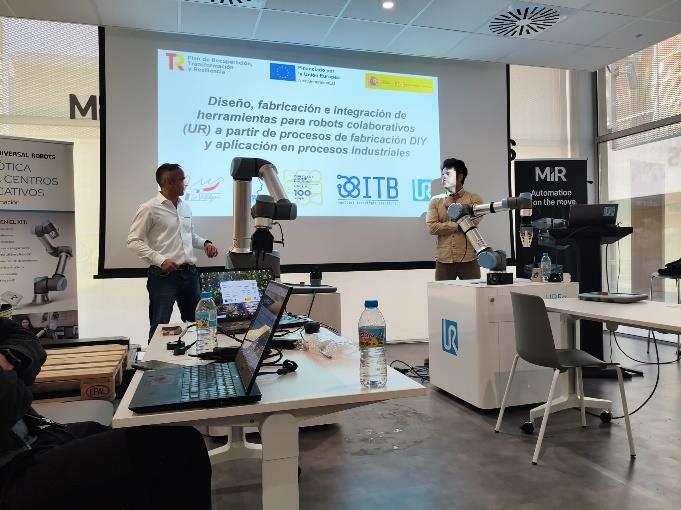
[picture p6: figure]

Figura 9. Presentación proyecto en sede de Universal Robots Barcelona.

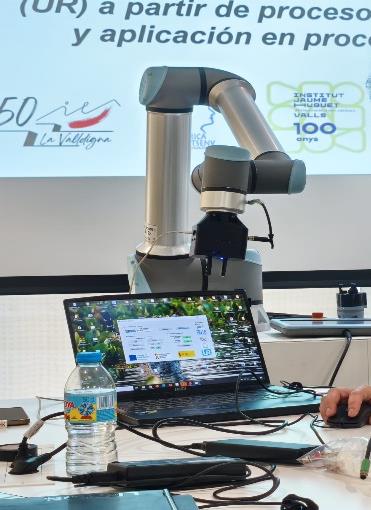
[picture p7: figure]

Figura 10. Presentación proyecto en sede de Universal Robots Barcelona herramienta.

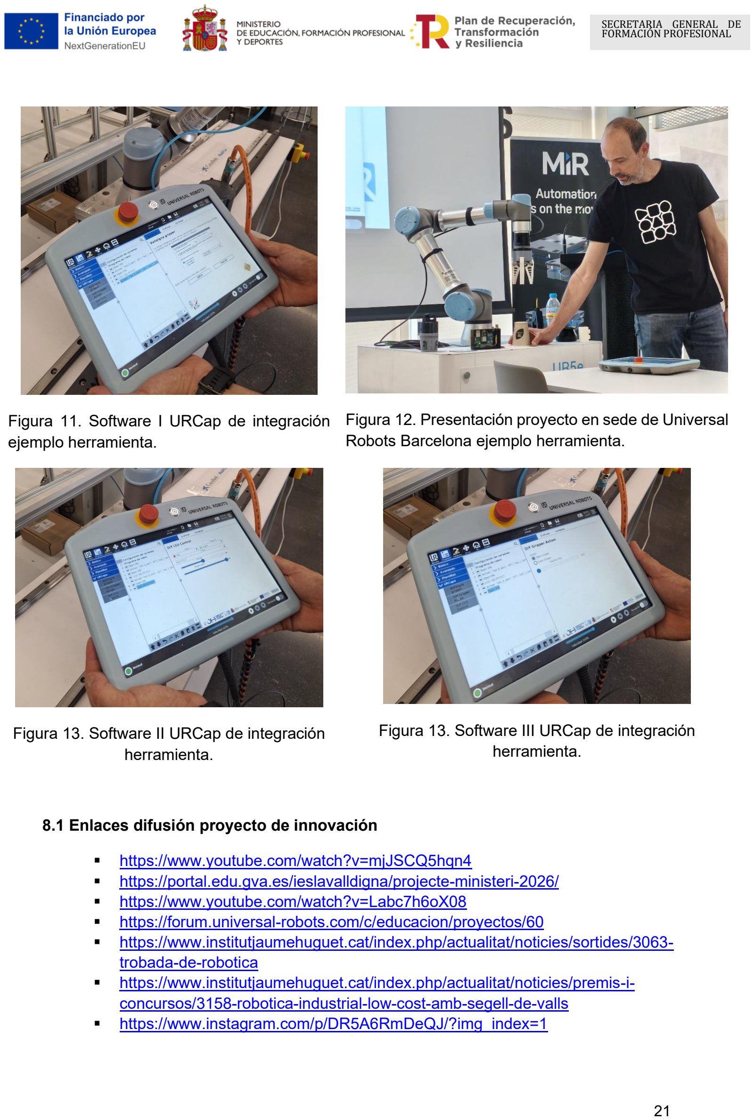
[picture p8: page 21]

Figura 11. Software I URCap de integración ejemplo herramienta.

Figura 12. Presentación proyecto en sede de Universal Robots Barcelona ejemplo herramienta.

Figura 13. Software II URCap de integración herramienta.

Figura 13. Software III URCap de integración herramienta.

### 8.1 Enlaces difusión proyecto de innovación

- https://www.youtube.com/watch?v=mjJSCQ5hqn4
- https://portal.edu.gva.es/ieslavalldigna/projecte-ministeri-2026/
- https://www.youtube.com/watch?v=Labc7h6oX08
- https://forum.universal-robots.com/c/educacion/proyectos/60
- https://www.institutjaumehuguet.cat/index.php/actualitat/noticies/sortides/3063-trobada-de-robotica (https://www.institutjaumehuguet.cat/index.php/actualitat/noticies/sortides/3063-trobada-de-robotica)
- https://www.institutjaumehuguet.cat/index.php/actualitat/noticies/premis-i-concursos/3158-robotica-industrial-low-cost-amb-segell-de-valls (https://www.institutjaumehuguet.cat/index.php/actualitat/noticies/premis-i-concursos/3158-robotica-industrial-low-cost-amb-segell-de-valls)
- https://www.instagram.com/p/DR5A6RmDeQJ/?img_index=1

- https://www.instagram.com/p/DXYxgqrDW8o/?img_index=1
- https://www.instagram.com/p/DYeQOP4jAzD/?igsh=dHZ6eGRoeHZvZmFm

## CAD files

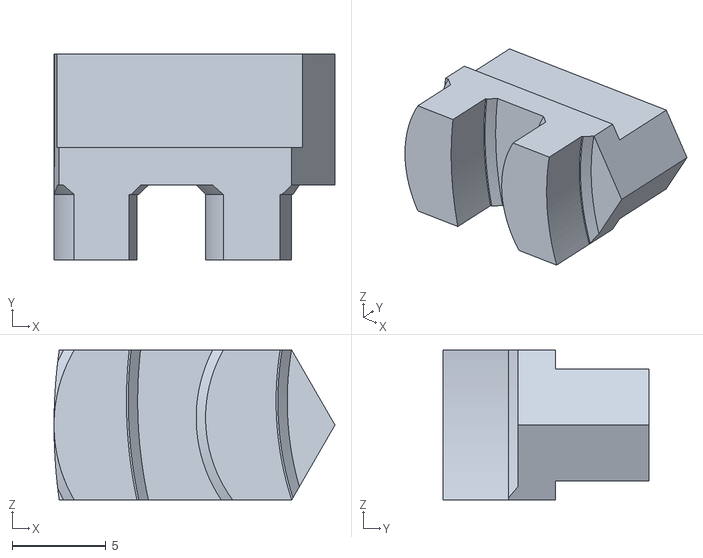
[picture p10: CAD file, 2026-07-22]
mecanica/Grapa_A_V2.stl
15.0 x 11.0 x 8.00

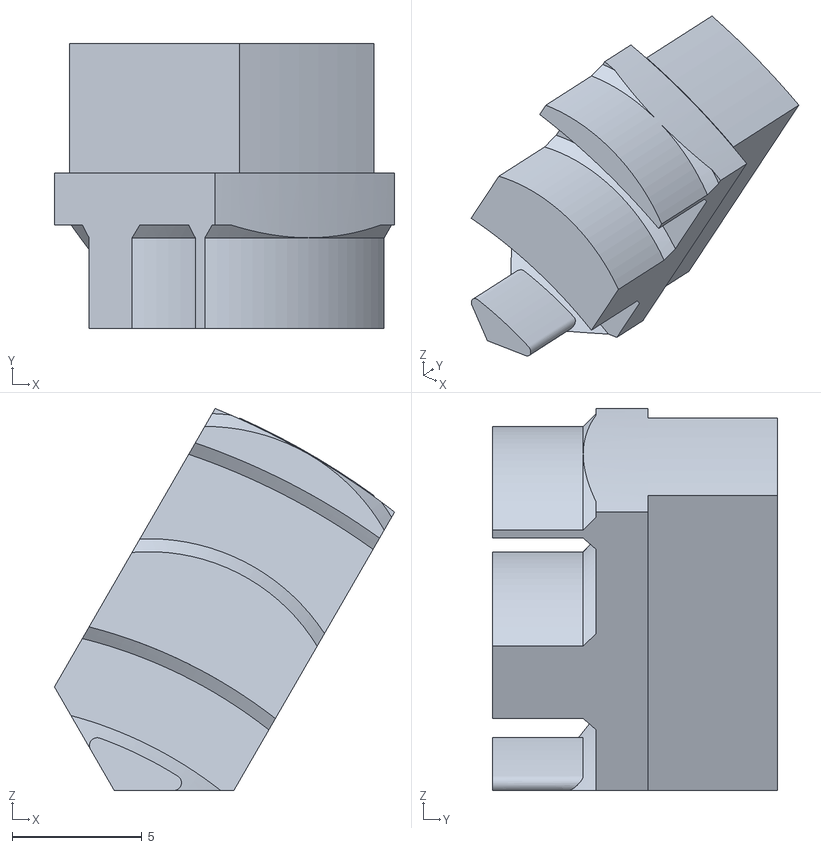
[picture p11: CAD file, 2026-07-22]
mecanica/Grapa_B_V2.stl
13.1 x 11.0 x 14.7

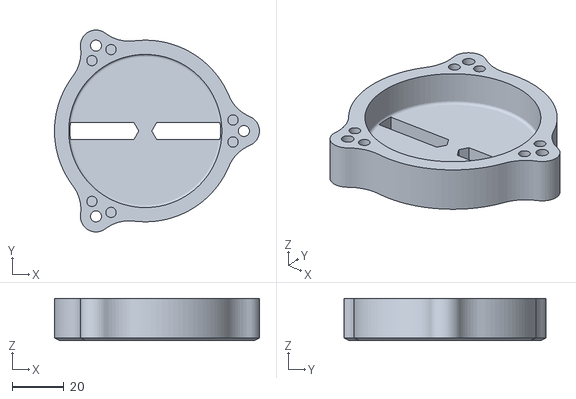
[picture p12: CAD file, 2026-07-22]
mecanica/LID_Gripper_2Fingers_V1.stl
79.0 x 77.8 x 16.2

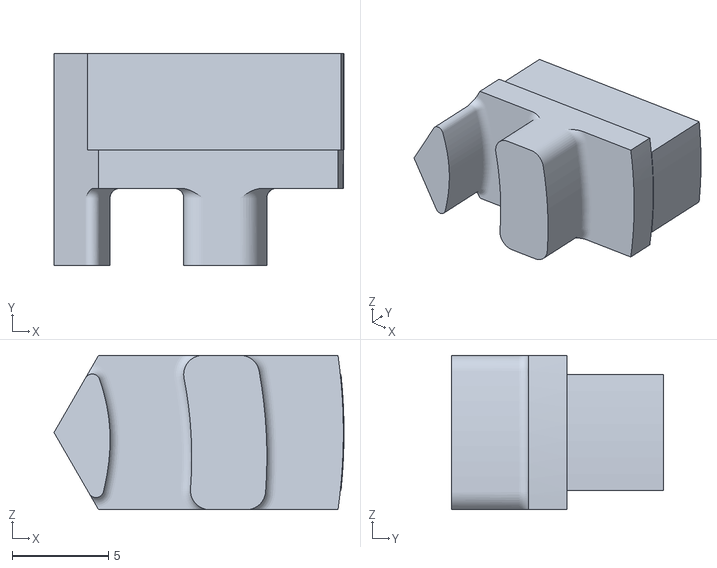
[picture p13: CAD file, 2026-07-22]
mecanica/Gripper_2Fingers_B_V1.stl
15.0 x 11.0 x 8.00

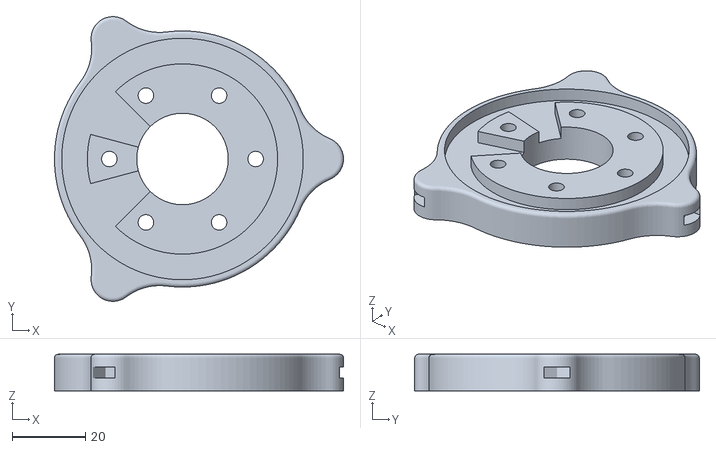
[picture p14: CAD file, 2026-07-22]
mecanica/Base_Gripper_V1_B.stl
79.0 x 77.8 x 10.0

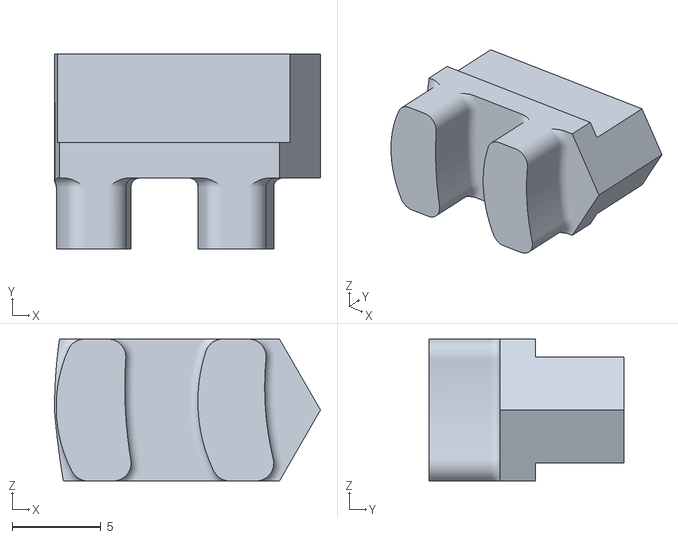
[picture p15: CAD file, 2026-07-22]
mecanica/Gripper_2Fingers_A_V1.stl
15.0 x 11.0 x 8.00

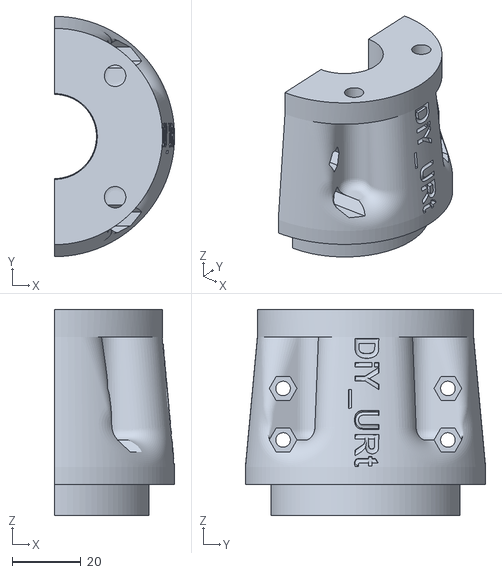
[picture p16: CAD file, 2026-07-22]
mecanica/Base_Gripper_V1_A.stl
35.0 x 70.0 x 60.0

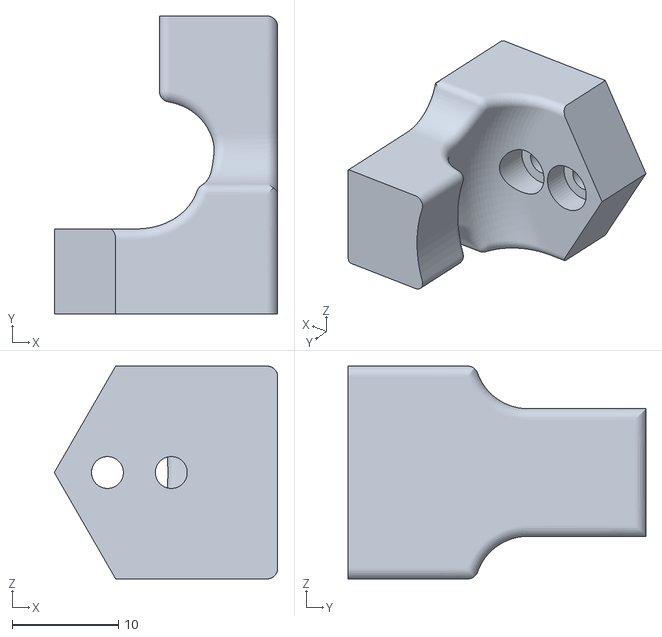
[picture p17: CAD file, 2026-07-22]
mecanica/Finger_V3.stl
21.0 x 28.0 x 20.0

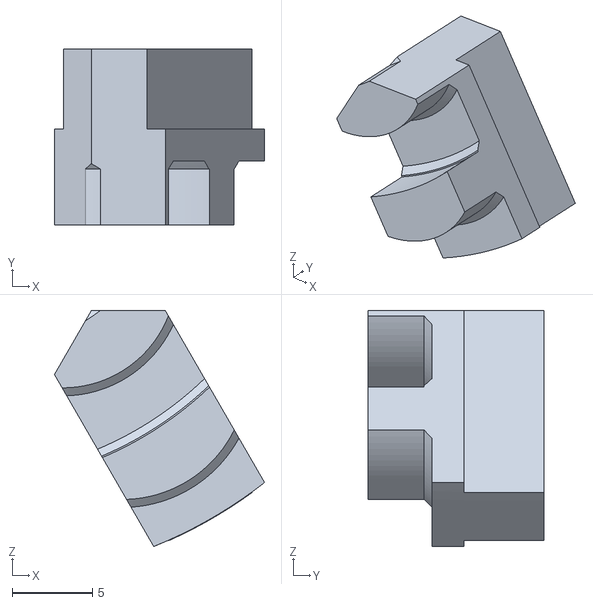
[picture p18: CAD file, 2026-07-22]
mecanica/Grapa_C_V2.stl
13.1 x 11.0 x 14.7

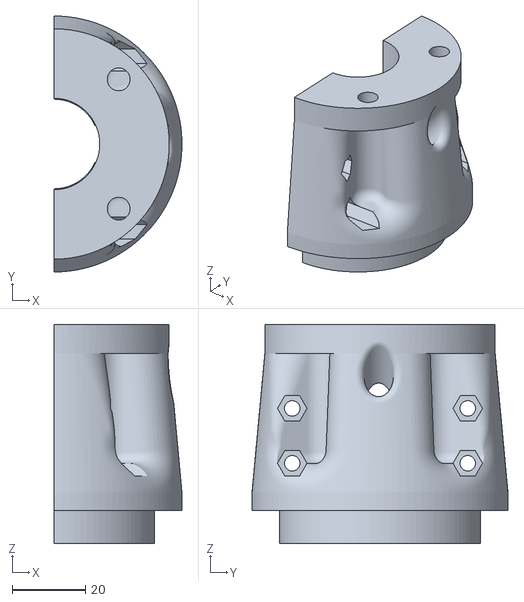
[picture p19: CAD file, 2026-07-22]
mecanica/Base_Gripper_V1_C.stl
35.0 x 70.0 x 60.0

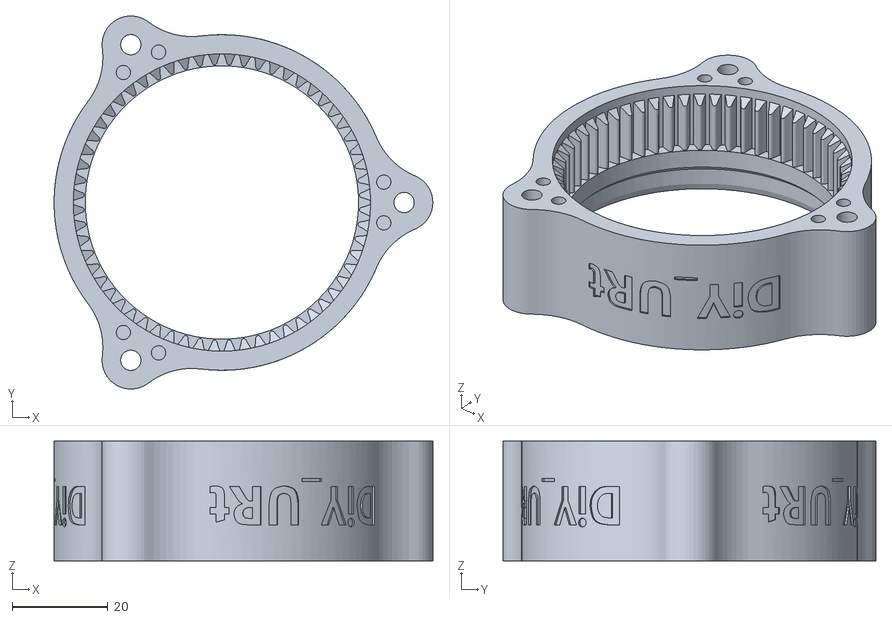
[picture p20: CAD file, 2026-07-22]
mecanica/Culata_TOP_gripper_gear_V1.stl
79.0 x 77.8 x 25.0

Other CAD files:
mecanica/Culata_TOP_gripper_V1.stl

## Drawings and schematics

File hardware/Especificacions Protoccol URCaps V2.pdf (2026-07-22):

## Nova URCap

•Close | Open

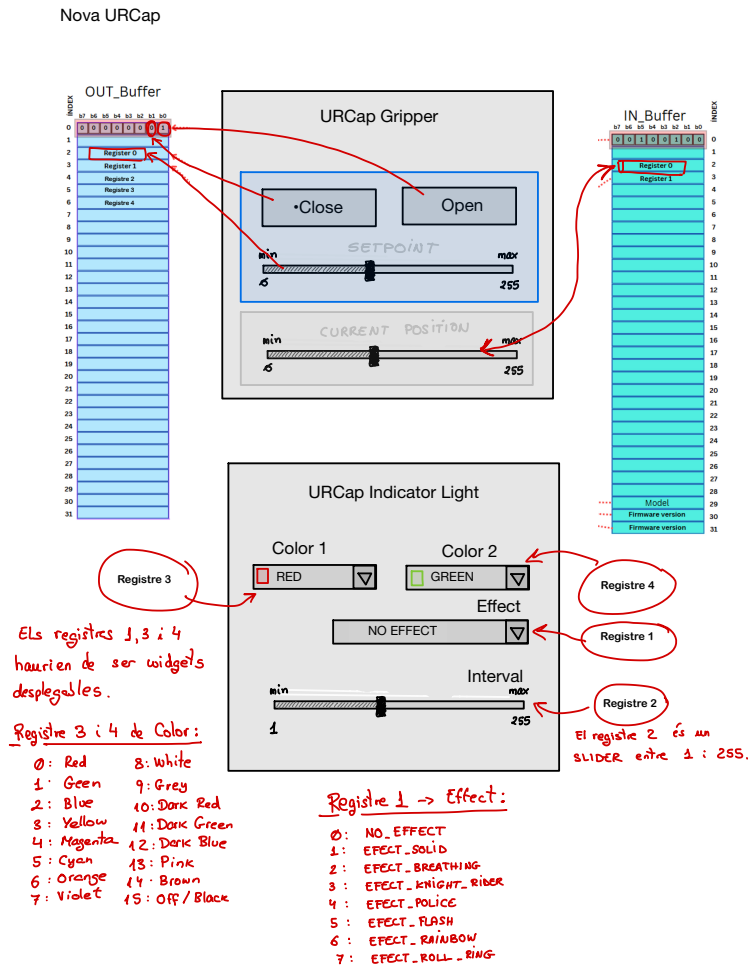
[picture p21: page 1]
URCap Gripper; Color 1; Color 2; RED; GREEN; Effect; NO EFFECT; Interval; Registre 2; Registre 3; Registre 4; Registre 1; & SETPOINT; S min; max; CURRENT; POSITION; 1,³ widgets; micr1111111111111111111111; Registre 3 i 4 de Color :; El registre 2; Red; 8: White; SLIDER; ente; Geen; 9 : Grey; Blue; 10: Dark Red; Regin stre ¹ - Effect :; Yellow; 1) 1 : Dark Green; EFFECT; Magenta 12 : Dark Blue; EFECT -; SOLID; 5 : Cyan; Pink; EFECT _; BREATHING; 6 : Orange; Brown; KNIGHT_; RIDER; Violet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

URCap Indicator Light

Els registres
haurien de ser
max desplegables .

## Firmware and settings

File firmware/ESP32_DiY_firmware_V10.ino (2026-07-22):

#include "DiY_URtool.h"
#include "MotorControl.h"
#include "EffectsEngine.h"

byte mac[] = { 0xDE, 0xAD, 0xBE, 0xEF, 0xFE, 0x01 };

enum ToolStatusID {
  NORMAL_MODE,
  CONFIGURATION_MODE,
  RESET_MODE,
};

ToolStatusID currentToolStatus = NORMAL_MODE;
DiY_URtool ur(mac, 30002, 5);

// --- PINS DEL SISTEMA ---
#define PIN_ENCODER_A 32
#define PIN_ENCODER_B 33
#define PIN_PWM_MOTOR 25
#define PIN_DIR1 26
#define PIN_DIR2 27
#define PIN_CORRENT 34  // ADC1, segur amb WiFi
#define PIN_LEDS 22
#define LED_COUNT 24

EffectsEngine effects(LED_COUNT, PIN_LEDS);
// Pins: A, B, PWM, Dir1, Dir2, Corrent
MotorControl pinces(PIN_ENCODER_A, PIN_ENCODER_B, PIN_PWM_MOTOR, PIN_DIR1, PIN_DIR2, PIN_CORRENT);

unsigned long old_time = 0;
bool f_Open_Gripper = false;
bool Open_Gripper_Old = false;
bool f_Close_Gripper = false;
bool Close_Gripper_Old = false;
bool Openning_Gripper_Old = false;
bool Closing_Gripper_Old = false;


bool f_command = false;
uint8_t old_command = 0;

bool configStatus = false;
uint8_t effect_old = 0;


// Definició variables Digital Input
const int buttonPin = 13;
const unsigned long debounceDelay = 50;
const unsigned long longPressTime = 2000;
const unsigned long longPressResetTime = 10000;

bool lastStableState = HIGH;
bool lastReading = HIGH;
unsigned long lastDebounceTime = 0;
unsigned long pressStartTime = 0;
bool longPressHandled = false;
bool longPressResetHandled = false;



void setup() {
  Serial.begin(115200);
  ur.begin();
  pinces.begin();
  effects.begin();

  Serial.print("IP asignada: ");
  Serial.println(Ethernet.localIP());

  // Tuning (Sintonitza aquests valors!)
  pinces.setPID(0.4, 0.05, 2.0);
  pinces.setForceLimit(0.5);     // Màxim corrent permès
  pinces.setGripThreshold(1.0);  // Corrent per detectar peça
  pinces.setMaxAccel(8);
  pinces.setDeadband(50);

  pinMode(buttonPin, INPUT_PULLUP);
}

void loop() {
  polling();

  ur.handler();      // Supervision comunication over TCP/IP
  pinces.handler();  // Supervision Gripper Motion Control
  selectEffect();
  gripperFunction();

  switch (currentToolStatus) {
    case NORMAL_MODE:
      break;
    case CONFIGURATION_MODE:
      ur.handleSerialCommands();
      break;
    case RESET_MODE:
      ESP.restart();
      break;
    default:
      currentToolStatus = NORMAL_MODE;
      break;
  }


  effects.update();  // Supervision Indicator Light Effects
}

void gripperFunction() {
  if ((ur.getInByte(0) & 0x01) && !Open_Gripper_Old) {  // Open Flag detectet
    //pinces.openGripper(map(ur.getInByte(2), 0, 255, 0, 100));
    pinces.openGripper(ur.getInByte(2));
  }
  Open_Gripper_Old = ur.getInByte(0) & 0x01;
  if ((ur.getInByte(0) & 0x02) && !Close_Gripper_Old) {  // Open Flag detectet
    //pinces.openGripper(map(ur.getInByte(2), 0, 255, 0, 100));
    pinces.closeGripper(ur.getInByte(2));
  }
  Close_Gripper_Old = ur.getInByte(0) & 0x02;

  if ((ur.getInByte(0) & 0x04) && !Openning_Gripper_Old) {
    Serial.println("Openning Press detectada!");
    pinces.openGripperManual();
  }
  if (!(ur.getInByte(0) & 0x04) && Openning_Gripper_Old){
    Serial.println("Opening Release detectada!");
    pinces.stopGripper();
  }
  if ((ur.getInByte(0) & 0x04) && Openning_Gripper_Old) {
    // Control dels límits
    ;
  }
  if ((ur.getInByte(0) & 0x04)) Openning_Gripper_Old = true;
  else Openning_Gripper_Old = false;

  if ((ur.getInByte(0) & 0x08) && !Closing_Gripper_Old){
    Serial.println("Closing Press detectada!");
    pinces.closeGripperManual();
  }
  if (!(ur.getInByte(0) & 0x08) && Closing_Gripper_Old){
    Serial.println("Closing Release detectada!");
    pinces.stopGripper();
  }
  if ((ur.getInByte(0) & 0x08) && Closing_Gripper_Old) {
    // Control dels límits
    ;
  }
  if ((ur.getInByte(0) & 0x08)) Closing_Gripper_Old = true;
  else Closing_Gripper_Old = false;
  
}

void selectEffect() {
  // EFFECTS LIGHT INDICATOR
  uint8_t effect = ur.getInByte(3);
  effects.setColor_1(ur.getInByte(5));
  effects.setColor_2(ur.getInByte(6));
  effects.setInterval(ur.getInByte(4));
  effects.setBrightness(255);
  //effects.setBrightness(ur.getInByte(7));
  if (effect != effect_old) {

    switch (effect) {
      case 0:
        effects.setEffect(NO_EFFECT);
        break;

      case 1:
        effects.setEffect(EFFECT_SOLID);
        break;

      case 2:
        effects.setEffect(EFFECT_BREATHING);
        break;

      case 3:
        effects.setEffect(EFFECT_KNIGHT_RIDER);
        break;

      case 4:
        effects.setEffect(EFFECT_POLICE);
        break;

      case 5:
        effects.setEffect(EFFECT_FLASH);
        break;
      case 6:
        effects.setEffect(EFFECT_RAINBOW);
        break;

      case 7:
        effects.setEffect(EFFECT_ROLL_RING);
        break;

      default:
        effects.setEffect(NO_EFFECT);
        break;
    }
  }
  effect_old = effect;
}


void polling() {
  bool reading = digitalRead(buttonPin);

  // Debounce
  if (reading != lastReading) {
    lastDebounceTime = millis();
  }

  if ((millis() - lastDebounceTime) > debounceDelay) {
    if (reading != lastStableState) {
      lastStableState = reading;

      if (lastStableState == LOW) {  // Botó premut
        pressStartTime = millis();
        longPressHandled = false;
        longPressResetHandled = false;
      } else {  // Botó alliberat
        longPressHandled = false;
        longPressResetHandled = false;
      }
    }
  }

  // Comprovació de long press
  if (lastStableState == LOW && !longPressHandled) {
    if (millis() - pressStartTime >= longPressTime) {
      onLongPress();
      longPressHandled = true;  // Evita múltiples crides
    }
  }

  // Comprovació de long press Reset
  if (lastStableState == LOW && !longPressResetHandled) {
    if (millis() - pressStartTime >= longPressResetTime) {
      onLongPressReset();
      longPressResetHandled = true;  // Evita múltiples crides
    }
  }

  lastReading = reading;
}

void onLongPress() {
  configStatus = !configStatus;
  if (configStatus) {
    currentToolStatus = CONFIGURATION_MODE;
  } else {
    currentToolStatus = NORMAL_MODE;
  }
}

void onLongPressReset() {
  currentToolStatus = RESET_MODE;
}

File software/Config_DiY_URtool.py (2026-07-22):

import tkinter as tk
from tkinter import ttk, messagebox
import serial.tools.list_ports
import serial
import time 
import sys 

class URToolConfigApp:
    def __init__(self, master):
        self.master = master
        master.title("⚙️ Configurador de Xarxa UR Tool")
        master.geometry("450x650")
        master.resizable(False, False)

        # --- Variables ---
        self.selected_port = tk.StringVar(master)
        self.ip_var = tk.StringVar(master, value="192.168.1.50")
        self.mask_var = tk.StringVar(master, value="255.255.255.0")
        self.gw_var = tk.StringVar(master, value="192.168.1.1")
        self.baud_rate = 115200
        self.serial_connection = None

        # --- Crear la interfície ---
        self.create_widgets()

    def create_widgets(self):
        main_frame = ttk.Frame(self.master, padding="15")
        main_frame.pack(fill='both', expand=True)

        # Configuració del Port Sèrie
        serial_group = ttk.LabelFrame(main_frame, text="🔌 Configuració Port Sèrie", padding="10")
        serial_group.pack(fill="x", pady=10)

        # 1. Selector de Port Sèrie
        ttk.Label(serial_group, text="Port Sèrie:").grid(row=0, column=0, padx=5, pady=5, sticky="w")
        self.port_combobox = ttk.Combobox(serial_group, textvariable=self.selected_port, state="readonly", width=30)
        self.port_combobox.grid(row=0, column=1, padx=5, pady=5, sticky="ew")
        self.port_combobox['values'] = self.list_serial_ports()
        
        if self.port_combobox['values']:
            self.selected_port.set(self.port_combobox['values'][0])

        # Botó d'actualització
        ttk.Button(serial_group, text="Actualitzar Llista", command=self.update_port_list).grid(row=0, column=2, padx=5, pady=5)
        
        serial_group.columnconfigure(1, weight=1)

        # Configuració de Xarxa
        network_group = ttk.LabelFrame(main_frame, text="🌐 Paràmetres de Xarxa (Ethernet)", padding="10")
        network_group.pack(fill="x", pady=10)

        # 2. IP
        ttk.Label(network_group, text="Adreça IP:").grid(row=0, column=0, padx=5, pady=5, sticky="w")
        ttk.Entry(network_group, textvariable=self.ip_var).grid(row=0, column=1, padx=5, pady=5, sticky="ew")

        # 3. MASK
        ttk.Label(network_group, text="Subnet Mask:").grid(row=1, column=0, padx=5, pady=5, sticky="w")
        ttk.Entry(network_group, textvariable=self.mask_var).grid(row=1, column=1, padx=5, pady=5, sticky="ew")

        # 4. Gateway
        ttk.Label(network_group, text="Gateway:").grid(row=2, column=0, padx=5, pady=5, sticky="w")
        ttk.Entry(network_group, textvariable=self.gw_var).grid(row=2, column=1, padx=5, pady=5, sticky="ew")
        
        network_group.columnconfigure(1, weight=1)

        # Botons d'Acció
        action_frame = ttk.Frame(main_frame)
        action_frame.pack(fill="x", pady=15)
        
        ttk.Button(action_frame, text="✔️ Enviar i Guardar (SAVE)", command=self.send_and_save, style='Accent.TButton').pack(side=tk.LEFT, expand=True, fill='x', padx=5)
        ttk.Button(action_frame, text="❓ Estat (STATUS)", command=self.get_status).pack(side=tk.LEFT, expand=True, fill='x', padx=5)

        # Àrea de Missatges
        message_group = ttk.LabelFrame(main_frame, text="💬 Registre de Comandes", padding="10")
        message_group.pack(fill="both", expand=True)
        
        self.message_text = tk.Text(message_group, height=8, state='disabled', wrap='word', bg='#e0e0e0', bd=0)
        self.message_text.pack(fill="both", expand=True)

        self.add_message("Benvingut! Selecciona el port i configura els paràmetres.")
        self.add_message("RECORDA: Després de guardar, has de reiniciar l'ESP32 per aplicar els canvis.")

    def list_serial_ports(self):
        """Llista els ports sèrie disponibles."""
        ports = serial.tools.list_ports.comports()
        return [port.device for port in ports]

    def update_port_list(self):
        """Actualitza la llista de ports al desplegable."""
        ports = self.list_serial_ports()
        self.port_combobox['values'] = ports
        if ports:
            self.selected_port.set(ports[0])
            self.add_message(f"Llista de ports actualitzada: {ports}")
        else:
            self.selected_port.set('')
            self.add_message("No s'han trobat ports sèrie.")

    def open_serial_connection(self):
        """Obre la connexió serial, reinicia l'ESP32 i espera el boot."""
        port = self.selected_port.get()
        if not port:
            messagebox.showerror("Error de Connexió", "Si us plau, selecciona un port sèrie.")
            return False

        if self.serial_connection and self.serial_connection.is_open:
            return True

        try:
            # 1. Obrir la connexió. Això normalment reinicia l'ESP32.
            self.serial_connection = serial.Serial(port, self.baud_rate, timeout=1)
            self.serial_connection.reset_input_buffer()
            self.serial_connection.reset_output_buffer()
            
            self.add_message(f"Connexió oberta a {port}. Reiniciant ESP32...")

            # 2. Esperar que l'ESP32 arrenqui completament (3 segons per seguretat).
            boot_delay = 3
            time.sleep(boot_delay) 
            
            # 3. Netejar els missatges de boot loader (com el 'rst:0x1')
            self.serial_connection.reset_input_buffer()
            self.add_message(f"Esperat {boot_delay} segons. ESP32 llest per rebre comandes.")
            
            return True
        except serial.SerialException as e:
            messagebox.showerror("Error de Connexió", f"No es pot obrir el port {port}: {e}")
            self.serial_connection = None
            return False

    def close_serial_connection(self):
        """Tanca la connexió serial."""
        if self.serial_connection and self.serial_connection.is_open:
            self.serial_connection.close()
            self.serial_connection = None
            self.add_message("Connexió serial tancada.")

    def send_command(self, command, expect_response=True):
        """Envia una comanda per serial i llegeix la resposta."""
        if not self.open_serial_connection():
            return ""

        try:
            # Enviar la comanda amb salt de línia
            self.serial_connection.write(f"{command}\n".encode())
            self.add_message(f"Enviant: {command}")
            
            if not expect_response:
                return ""
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

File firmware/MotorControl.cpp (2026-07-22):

#include "MotorControl.h"

MotorControl::MotorControl(uint8_t pA, uint8_t pB, uint8_t pPWM, uint8_t pD1, uint8_t pD2, uint8_t pCurr)
  : pinA(pA), pinB(pB), pinPWM(pPWM), pinDir1(pD1), pinDir2(pD2), pinCorrent(pCurr) {
  targetPos = 0;
  Kp = 1.0;
  Ki = 0.0;
  Kd = 0.0;
  errorIntegral = 0;
  errorAnterior = 0;
  correntLimit = 0.8;
  correntHoming = 0.3;
  correntLimitOpen = 0.3;
  correntLimitClose = 0.15;
  gripCurrentThreshold = 0.5;
  maxAccel = 5;
  currentPwm = 0;
  currentState = HOMING;
  deadband = 15;  // Valor per defecte
  firstStateCycle = true;
  overCurrent = false;
  movingTimeOut = 3800;  //(5 segons)
  lastTimeCounter = 0;
}

void MotorControl::begin() {
  pinMode(pinDir1, OUTPUT);
  pinMode(pinDir2, OUTPUT);

  // Inicialitzem l'encoder amb la llibreria (sense ISR!)
  encoder.attachFullQuad(pinA, pinB);
  encoder.setCount(0);

  ledcAttach(pinPWM, freq, resolucio);
}

void MotorControl::home() {
  currentState = HOMING;
  firstStateCycle = true;
  setTarget(-50000);
}

void MotorControl::setPID(float p, float i, float d) {
  Kp = p;
  Ki = i;
  Kd = d;
}
void MotorControl::setKp(float p) {
  Kp = p;
}
void MotorControl::setKi(float i) {
  Ki = i;
}
void MotorControl::setKd(float d) {
  Kd = d;
}
void MotorControl::setTarget(long target) {
  targetPos = target;
  errorIntegral = 0;
}
void MotorControl::setForceLimit(float amps) {
  correntLimit = amps;
}
void MotorControl::setGripThreshold(float amps) {
  gripCurrentThreshold = amps;
}
void MotorControl::setMaxAccel(int accel) {
  maxAccel = accel;
}

long MotorControl::getPosition() {
  return (long)encoder.getCount();
}

float MotorControl::getCurrent() {
  // Mitjana mòbil per eliminar soroll elèctric (Software Filter)
    long adcSum = 0;
    for(int i = 0; i < 8; i++) {
        adcSum += analogRead(pinCorrent);
    }
    return ((adcSum >> 3) * AnalogToVoltage);
    //return ((adcSum / 8.0) * 3.3 / 4095.0);

  //currentSum = (currentSum + (analogRead(pinCorrent) / 500.0)) * 0.5;
  //return ((adcSum / 8.0) / 500.0);
  //return currentSum;
}

float MotorControl::getCurrentSum() {
  return currentSum;
}

void MotorControl::setDeadband(int val) {
  deadband = val;
}

long MotorControl::directConvert(int percent) {
  if (percent > 100) percent = 100;
  if (percent < 0) percent = 0;
  return 17000L - (long)percent * 170L;
}

int MotorControl::inversConvert(long ticks) {
  if (ticks > 17000) ticks = 17000;
  if (ticks < 0) ticks = 0;
  return (17000L - ticks) / 170L;
}

void MotorControl::stopGripper() {
  setTarget(encoder.getCount());
  ledcWrite(pinPWM, 0);
  digitalWrite(pinDir1, LOW);
  digitalWrite(pinDir2, LOW);
  currentPwm = 0;
  errorIntegral = 0;  // Netejem l'integral perquè no s'acumuli mentres parem
  currentState = IDLE;
}

void MotorControl::openGripper(int pos) {
  if (pos > 100) pos = 100;
  if (pos < 0) pos = 0;
  setTarget(directConvert(pos));
  currentState = OPENING;
  firstStateCycle = true;
}
void MotorControl::openGripperManual(){
  currentState = MANUAL_OPEN;
}

void MotorControl::closeGripper(int pos) {
  if (pos > 100) pos = 100;
  if (pos < 0) pos = 0;
  setTarget(directConvert(pos));
  currentState = CLOSING;
  firstStateCycle = true;
}

void MotorControl::closeGripperManual(){
  currentState = MANUAL_CLOSE;
}

void MotorControl::handler() {
  if (millis() - lastTick >= 10) {
    lastTick = millis();
    float current = getCurrent();
    long posicio = getPosition();  // Obtenim posició del hardware PCNT
    long error = targetPos - posicio;

    // 1. Lògica Homing
    if (currentState == HOMING) {

      if (firstStateCycle) {
        firstStateCycle = false;
        lastTimeCounter = millis();
        setTarget(-50000);
      }

      if (millis() - lastTimeCounter > 400) {
        if (((current > correntHoming) || (millis() - lastTimeCounter > movingTimeOut)) && !overCurrent) {
          overCurrent = true;
          encoder.setCount(-2000);
          setTarget(0);
        }
        if (overCurrent) {
          // --- LA ZONA MORTA ---
          if (abs(error) <= deadband) {
            // Estem prou a prop, parem el control
            stopGripper();
            overCurrent = false;
            //Serial.println("HOMING Done");
            return;  // Sortim del handler, no cal calcular PID
          }
        }
      }
    }

    // 2. Lògica IDLE
    if (currentState == IDLE) {
      ;
    }

    // 3. Lògica CLOSING
    if (currentState == CLOSING) {
      if (firstStateCycle) {
        firstStateCycle = false;
        lastTimeCounter = millis();
      }
      if (millis() - lastTimeCounter > 400) {
        if (current > correntLimitClose) {
          //Serial.printf("overCurrent detectat -> setPoint:%d, actualPos:%d\n", inversConvert(targetPos), inversConvert(getPosition()));
          stopGripper();
          return;  // Sortim del handler, no cal calcular PID
        }
        if (millis() - lastTimeCounter > movingTimeOut) {
        //Serial.printf("timeOut detectat -> setPoint:%d, actualPos:%d\n", inversConvert(targetPos), inversConvert(getPosition()));
          stopGripper();
          return;  // Sortim del handler, no cal calcular PID
        }
      }
      if (abs(error) <= deadband) {
        // Estem prou a prop, parem el control
        //Serial.println("CLOSING Done");
        stopGripper();
        return;  // Sortim del handler, no cal calcular PID
      }
    }

    // 4. Lògica OPENING
    if (currentState == OPENING) {
      if (firstStateCycle) {
        firstStateCycle = false;
        lastTimeCounter = millis();
      }
      if (millis() - lastTimeCounter > 400) {
        if (current > correntLimitOpen) {
          //Serial.printf("overCurrent detectat -> setPoint:%d, actualPos:%d\n", inversConvert(targetPos), inversConvert(getPosition()));
          stopGripper();
          return;  // Sortim del handler, no cal calcular PID
        }
        if (millis() - lastTimeCounter > movingTimeOut) {
          //Serial.printf("timeOut detectat -> setPoint:%d, actualPos:%d\n", inversConvert(targetPos), inversConvert(getPosition()));
          stopGripper();
          return;  // Sortim del handler, no cal calcular PID
        }
      }
      if (abs(error) <= deadband) {
        // Estem prou a prop, parem el control
        //Serial.println("OPENING Done");
        stopGripper();
        return;  // Sortim del handler, no cal calcular PID
      }
    }

    
    // 5. Seguretat: Control de sobrecorrent
    if (current > correntLimit) {
      stopGripper();
      return;  // Sortim del handler, no cal calcular PID
    }


    // 6. PID
    if (currentState != IDLE && currentState != MANUAL_CLOSE && currentState != MANUAL_OPEN) {
      errorIntegral = constrain(errorIntegral + error, -500, 500);
      float pidOutput = (Kp * error) + (Ki * errorIntegral) + (Kd * (error - errorAnterior));
      errorAnterior = error;
      pidOutput = constrain(pidOutput, -255, 255);  // Important per no saturar
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

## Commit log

2026-07-22 Primera versió
    [Base_Gripper_V1_A.stl, Base_Gripper_V1_B.stl, Base_Gripper_V1_C.stl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]
2026-07-22 He afegit la URcap 2.0.3
